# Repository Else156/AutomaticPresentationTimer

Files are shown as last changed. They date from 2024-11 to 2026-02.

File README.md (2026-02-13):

# 物理ベル式 プレゼンテーションタイマー 

Raspberry Pi Pico、SSD1306 OLEDディスプレイ、ソレノイド、およびチンベルを使用したプレゼンテーションタイマーです。
設定した時間（例：予鈴、中間鈴、終了鈴）になると、物理的なベルを「チン！」と鳴らして知らせます。
操作にはRGBロータリーエンコーダを使用し、直感的なメニュー操作と時間設定が可能です。

## ✨ 特徴

* **物理ベル鳴動**: ソレノイドを使用し、設定時間にチンベルを鳴らします。
* **3段階のアラーム設定**: 1回目（1回鳴る）、2回目（2回鳴る）、終了時（3回鳴る）の時間を個別に設定可能。
* **直感的なUI**: ロータリーエンコーダを回して選択・数値変更、押し込んで決定。
* **設定保存機能**: 設定した時間は内蔵フラッシュに保存され、電源を切っても保持されます。
* **加速スクロール**: 時間設定時、エンコーダを速く回すと数値が大きく変化する加速処理を搭載。
* **OLEDディスプレイ**: 現在の残り時間、設定状態、操作ガイドを分かりやすく表示。

## 🛠 ハードウェア構成

### 使用部品

| 部品名 | 型番 | URL | 備考 |
| :--- | :--- | :--- | :--- |
| Raspberry Pi Pico | SC0915 | [購入先URL](https://akizukidenshi.com/catalog/g/g116132/) | |
| 有機ELディスプレイ(OLED) 白色 |  | [購入先URL](https://akizukidenshi.com/catalog/g/g112031/)| |
| イルミネーションロータリーエンコーダ用ピッチ変換基板 | SFE-BOB-11722 | [購入先URL](https://www.switch-science.com/products/1308?srsltid=AfmBOopGGrrqZFvyvS5xYhzGZG8HVmHDNQKUY4yKhhwYDoHrCVhfIAhd) | 廃盤だが千石電商では販売(2026年1月時点） |
| ソレノイド | ZHO-0420S-05A4.5(5V) | [購入先URL](https://akizukidenshi.com/catalog/g/g110761//) | |
| NchパワーMOSFET | 2SK4017(Q) | [購入先URL](https://akizukidenshi.com/catalog/g/g107597/) | |
| カーボン抵抗　10kΩ | RD25S 10K | [購入先URL](https://akizukidenshi.com/catalog/g/g125103/) | |
| 汎用整流用ダイオード 1000V1A | 1N4007-B | [購入先URL](https://akizukidenshi.com/catalog/g/g108327/) | |
| 電解コンデンサー1000μF35V | 35ZLH1000MEFC12.5X20 | [購入先URL](https://akizukidenshi.com/catalog/g/g102722/) | |
| チェック端子(テストポイント) | TEST-22 | [購入先URL](https://akizukidenshi.com/catalog/g/g112216/) | |
| チンベル（卓上ベル） |  |  | |

### 🔌 配線 (Pinout)

`hardware.py` のデフォルト設定に基づく配線図です。

| 部品 | ピン名 | Pico GPIO | 備考 |
| :--- | :--- | :--- | :--- |
| **OLED (I2C)** | SDA | GP0 | |
| | SCL | GP1 | |
| | VCC/GND | - | 3.3V / GND |
| **Encoder** | A相 (CLK) | GP10 | Pull-Up設定 |
| | B相 (DT) | GP11 | Pull-Up設定 |
| | Switch (SW)| GP12 | Pull-Up設定 (Active Low) |
| | GND | - | 共通GND |
| **Solenoid** | Gate/Base | GP15 | **要ドライバ回路** |

> [!WARNING]
> **警告**: ソレノイドをGPIOピン(GP15)に直接接続しないでください。過電流と逆起電力によりPicoが破損します。必ずMOSFET等を使用したドライバ回路と、保護用ダイオードを組み込んでください。

## 📂 ファイル構成

プロジェクトは機能ごとにモジュール化されています。

```text
.
├── circuit/                               # 回路設計関連
│   ├── AutomaticPresentationTimer_v1.0    # Kicadデータが格納
|   └── library/KiCad-RP-Pico-main         # Kicadでの使用ライブラリが格納
├── src/                       # ソースコード
│   ├── main.py                # エントリーポイント。状態遷移と設定の保存/読込を管理
│   ├── hardware.py            # GPIO制御（ソレノイド、エンコーダ、ボタン）
│   ├── display.py             # SSD1306への描画処理
│   ├── presentation_timer_mode.py # タイマー計測・実行モードのロジック
│   ├── setting_mode.py        # メニュー選択モードのロジック
│   ├── edit_mode.py           # 時間設定変更モードのロジック
|   └── settings.json          # 設定保存ファイル (初回実行時に自動生成)
└── README.md
```

> [!WARNING]
> **警告**: プログラムを実行する場合は、ディスプレイ用ドライバライブラリとしてssd1306.pyを得る必要があります。

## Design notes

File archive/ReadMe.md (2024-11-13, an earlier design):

# 自動プレゼンテーションタイマー
## 仕様について
|機器 |型番 |価格 |URL |
|---|---|---|---|
|マイコン |Raspberry Pi Pico |770円 |https://akizukidenshi.com/catalog/g/g116132/ |
|ディスプレイ |SC1602BSLB-XA-GB-K　|980円(購入済み) |https://akizukidenshi.com/catalog/g/g100038/　|
|ソレノイド |ZHO-0420S-05A4.5(5V)　|750円(購入済み) |https://akizukidenshi.com/catalog/g/g110761/|
|MOSFET |IRLU3410PBF　|100円 |https://akizukidenshi.com/catalog/g/g106025/
|整流用ダイオード |1000V1A 1N4007-B　|100円 |https://akizukidenshi.com/catalog/g/g108327/

## 開発環境について
### 仮想環境の導入方法
```
source .venv/bin/activate
```

### ライブラリのインストール
```
pip install -r requirements.txt
```

### VS Code の拡張機能のインストール
1. MicroPico のインストール
VS Code の 拡張機能 をクリックし、 micropico と入力して検索します。<br>
インストール をクリックして、拡張機能をインストールします。


2. MicroPico の初期設定
VS Code の 表示(V) → コマンドパレット をクリックします。<br>

MicroPico: Configure project と入力して Enter キー を押下します。


参考資料は以下に示す<br>
https://qiita.com/IoriGunji/items/ebe6cefd3562639f7ca2

### Raspberry Pi Pico の準備
1. ファームウェアのダウンロード
Raspberry Pi 財団のサイトからファームウェアをダウンロードします。<br>
Raspberry Pi Pico を選んでください。<br>
https://www.raspberrypi.com/documentation/microcontrollers/micropython.html#drag-and-drop-micropython


2. ファームウェアの書き込み
Raspberry Pi Pico の BOOTSET ボタンを押しながら、 USB ケーブルで PC に接続します。

ダウンロードしたファームウェアを RPI-RP2 にドロップします。

ファームウェアの転送が完了すると、 Raspberry Pi Pico が自動的に再起動します。<br>
以上で、ファームウェアの書き込みは完了です。<br>
以降は USB シリアル通信経由で REPL にアクセスできます。<br>

参考資料は以下に示す<br>
https://qiita.com/IoriGunji/items/ebe6cefd3562639f7ca2

## Python コードの実行準備
Raspberry Pi Pico を USB ケーブルで PC に接続します。（※ BOOTSET ボタンは押しません）<br>
VS Code のステータスバーの Toggle board connection ボタンが Pico Connected になっていることを確認します。
Pico Disconnected になっている場合はクリックして Raspberry Pi Pico に接続します。

VS Code のステータスバーの Run current file ボタンをクリックして、実行します。
ボタンの表記が Run から Stop に変わります。

Raspberry Pi Pico 本体の LED が点滅することを確認します。

参考資料は以下に示す<br>
https://qiita.com/IoriGunji/items/ebe6cefd3562639f7ca2

## Pythonコードの書き込み
VS Code の 表示(V) をクリックします。

コマンドパレット をクリックします。

`>MicroPico: Upload current file to Pico` と入力して、 Enter キー を押下します。

参考資料は以下に示す<br>
https://qiita.com/IoriGunji/items/ebe6cefd3562639f7ca2

## Pythonコードの実行（スタンドアローン）
Raspberry Pi Pico の USB ケーブルを PC から外し、 USB 充電器やモバイルバッテリーなどに接続します。<br>
LED が点滅すれば OK です。<br>
参考資料は以下に示す<br>
https://qiita.com/IoriGunji/items/ebe6cefd3562639f7ca2

## 参考文献
### Raspberry Pi Picoについて
https://sozorablog.com/raspberry-pi-pico/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
### ソレノイドの回路など
https://highso.hatenablog.com/entry/2019/02/25/180000
https://ameblo.jp/solcon/entry-12278991497.html

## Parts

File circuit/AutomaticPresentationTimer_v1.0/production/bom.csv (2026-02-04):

Designator | Footprint | Quantity | Value | LCSC Part #
C1 | CP_Radial_D10.0mm_P5.00mm | 1 | 1000µF 16V
D1 | D_DO-41_SOD81_P10.16mm_Horizontal | 1 | D
H1, H2, H3, H4 | MountingHole_3.2mm_M3 | 4 | MountingHole
J1 | PinSocket_1x05_P2.54mm_Vertical | 1 | Conn_01x05
J2 | PinSocket_1x03_P2.54mm_Vertical | 1 | Conn_01x03
J3 | JST_PH_B2B-PH-K_1x02_P2.00mm_Vertical | 1 | ZHO-0420S-05A4.5(5V)
J4 | PinSocket_1x04_P2.54mm_Vertical | 1 | ディスプレイモジュール
Q1 | TO-251-3_Vertical | 1 | 2SK4017
R1 | R_Axial_DIN0207_L6.3mm_D2.5mm_P7.62mm_Horizontal | 1 | 10k
TP1 | TestPoint_THTPad_D2.0mm_Drill1.0mm | 1 | 5V
TP2 | TestPoint_THTPad_D2.0mm_Drill1.0mm | 1 | 3.3V
TP3 | TestPoint_THTPad_D2.0mm_Drill1.0mm | 1 | GND
TP4 | TestPoint_THTPad_D2.0mm_Drill1.0mm | 1 | SDA
TP5 | TestPoint_THTPad_D2.0mm_Drill1.0mm | 1 | SCL
TP6 | TestPoint_THTPad_D2.0mm_Drill1.0mm | 1 | GATE
U1 | RPi_Pico_SMD_TH | 1 | Pico

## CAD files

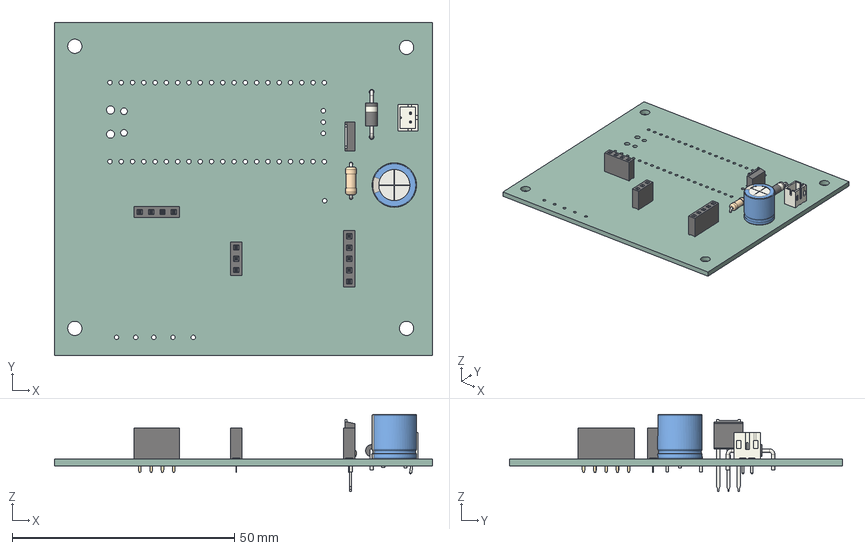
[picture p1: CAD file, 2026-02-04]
circuit/AutomaticPresentationTimer_v1.0/AutomaticPresentationTimer_v1.0.step
85.1 x 74.9 x 17.3 mm
R_Axial_DIN0207_L63mm_D25mm_P762mm_Horizontal
PinSocket_1x03_P254mm_Vertical
TO-251-3_Vertical
PinSocket_1x04_P254mm_Vertical
CP_Radial_D100mm_P500mm
PinSocket_1x05_P254mm_Vertical
D_DO-41_SOD81_P10.16mm_Horizontal
JST_B2B_PH_K
AutomaticPresentationTimer_v1.0_PCB

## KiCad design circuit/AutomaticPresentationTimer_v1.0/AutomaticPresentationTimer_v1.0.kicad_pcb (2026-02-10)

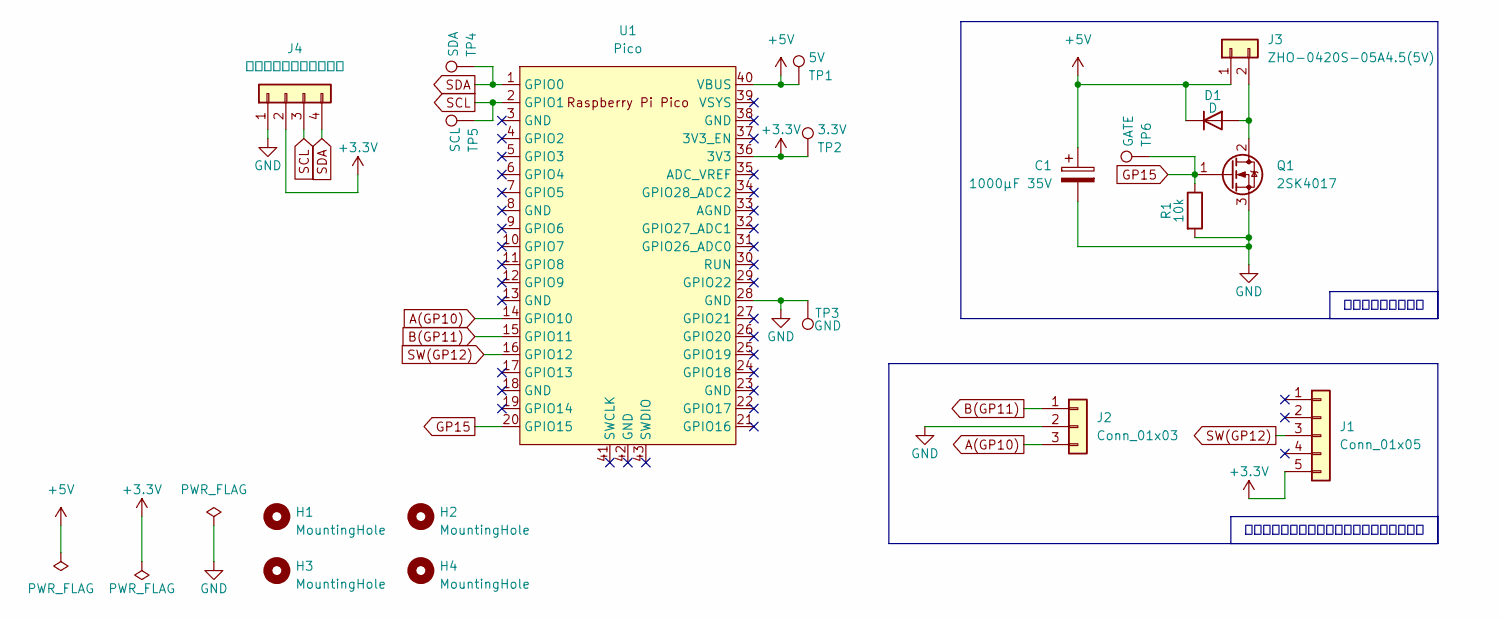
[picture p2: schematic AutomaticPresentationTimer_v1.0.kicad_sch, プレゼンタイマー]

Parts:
C1: 1000µF 35V; CP_Radial_D10.0mm_P5.00mm
D1: D; D_DO-41_SOD81_P10.16mm_Horizontal
H1, H2, H3, H4: MountingHole; MountingHole_3.2mm_M3
J1: Conn_01x05; PinSocket_1x05_P2.54mm_Vertical
J2: Conn_01x03; PinSocket_1x03_P2.54mm_Vertical
J3: ZHO-0420S-05A4.5(5V); JST_PH_B2B-PH-K_1x02_P2.00mm_Vertical
J4: ディスプレイモジュール; PinSocket_1x04_P2.54mm_Vertical
Q1: 2SK4017; TO-251-3_Vertical
R1: 10k; R_Axial_DIN0207_L6.3mm_D2.5mm_P7.62mm_Horizontal
TP1: 5V; TestPoint_THTPad_D2.0mm_Drill1.0mm
TP2: 3.3V; TestPoint_THTPad_D2.0mm_Drill1.0mm
TP3: GND; TestPoint_THTPad_D2.0mm_Drill1.0mm
TP4: SDA; TestPoint_THTPad_D2.0mm_Drill1.0mm
TP5: SCL; TestPoint_THTPad_D2.0mm_Drill1.0mm
TP6: GATE; TestPoint_THTPad_D2.0mm_Drill1.0mm
U1: Pico; RPi_Pico_SMD_TH

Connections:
+3.3V: J1.5, J4.2, TP2.1, U1.36 (3V3)
+5V: C1.1, D1.1 (K), J3.1, TP1.1, U1.40 (VBUS)
A(GP10): J2.3, U1.14 (GPIO10)
B(GP11): J2.1, U1.15 (GPIO11)
GND: C1.2, J2.2, J4.1, Q1.3 (S), R1.2, TP3.1, U1.28 (GND)
GP15: Q1.1 (G), R1.1, TP6.1, U1.20 (GPIO15)
unnamed: D1.2 (A), J3.2, Q1.2 (D)
SCL: J4.3, TP5.1, U1.2 (GPIO1)
SDA: J4.4, TP4.1, U1.1 (GPIO0)
SW(GP12): J1.3, U1.16 (GPIO12)

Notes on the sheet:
プッシュスイッチ付きロータリーエンコーダ
ソレノイド動作回路

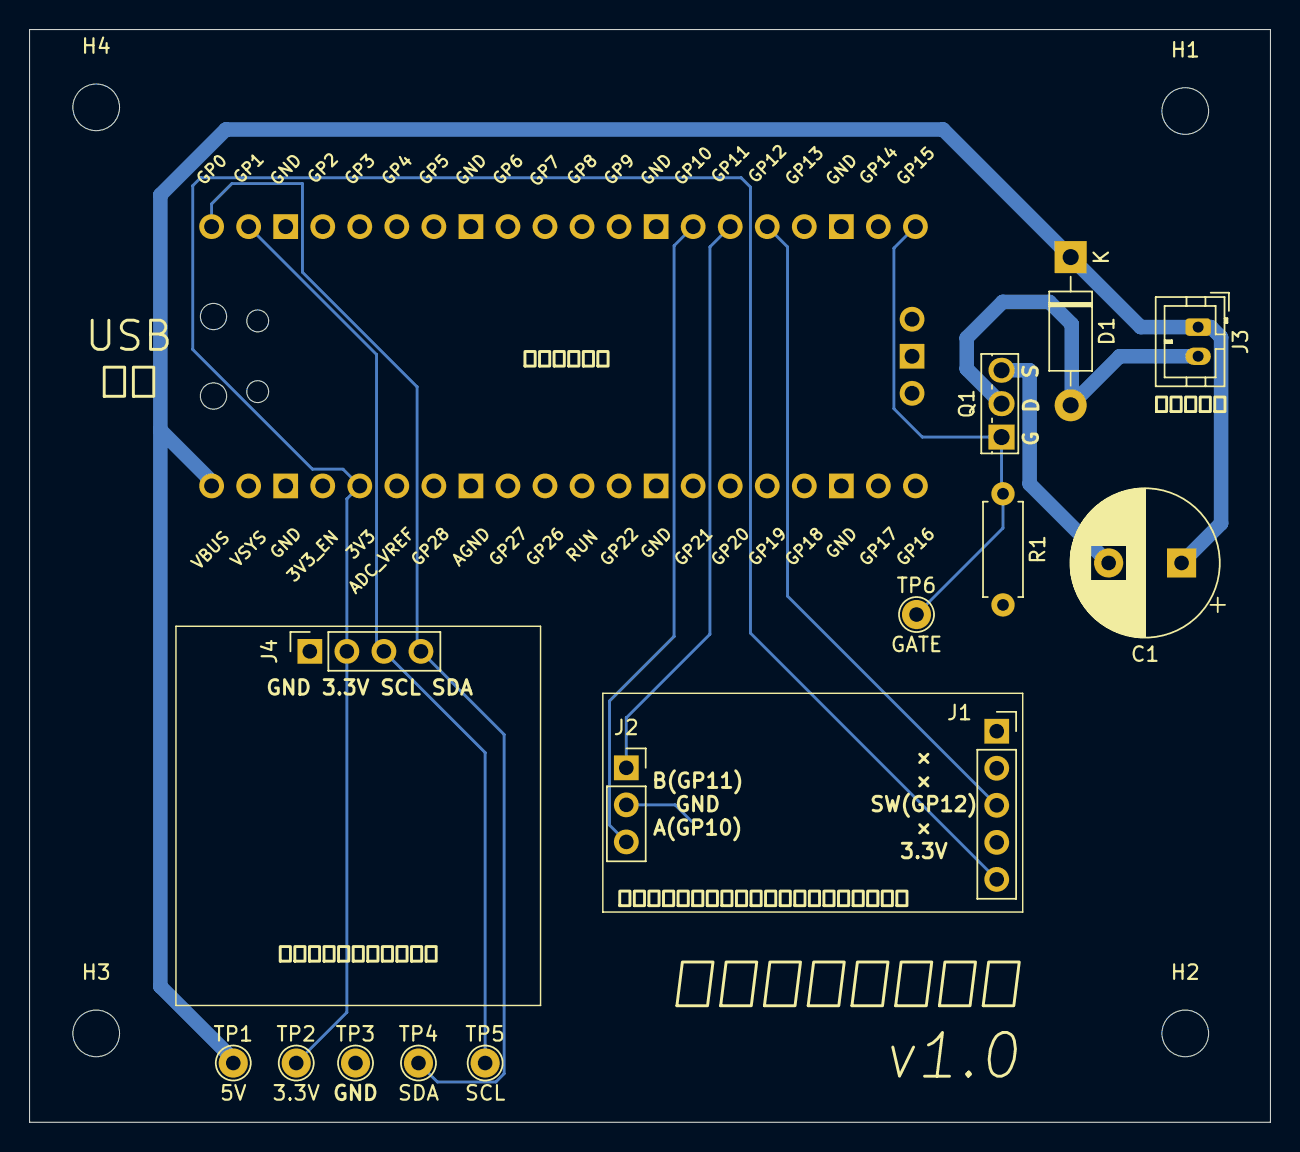
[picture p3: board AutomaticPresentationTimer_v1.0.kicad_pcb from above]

Board: 2 copper layers, 85.1 x 74.9 mm, 19 parts (1 on the bottom side), 10 nets.

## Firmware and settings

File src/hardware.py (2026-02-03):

import machine
import time

class HardwareInterface:
    """
    ハードウェア（GPIO）を管理するクラス
    - ソレノイドの駆動
    - RGBロータリーエンコーダの回転検知
    - エンコーダ内蔵ボタンのイベント検知
    """

    # --- ピン定義 (配線に合わせて変更してください) ---
    SOLENOID_PIN_NUM = 15   # ソレノイド
    
    # ロータリーエンコーダ用ピン
    ENC_A_PIN_NUM = 10      # 回転検知 A相 (CLK)
    ENC_B_PIN_NUM = 11      # 回転検知 B相 (DT)
    BUTTON_PIN_NUM = 12     # スイッチ (SW)

    # --- 設定値 ---
    SOLENOID_ON_MS = 60        # ソレノイド通電時間
    SOLENOID_INTERVAL_MS = 250 # 連打間隔
    
    LONG_PRESS_MS = 800     # 長押し閾値
    DEBOUNCE_MS = 50        # ボタンのチャタリング防止
    
    STEPS_PER_CLICK = 4     # ソレノイドの分解能(1クリックで内部カウンタがいくつ進むか)
    
    def __init__(self):
        # 1. ソレノイド初期化
        self.solenoid = machine.Pin(self.SOLENOID_PIN_NUM, machine.Pin.OUT)
        self.solenoid.value(0) 

        # 2. エンコーダ回転用ピン初期化 (PullUp推奨)
        self.enc_a = machine.Pin(self.ENC_A_PIN_NUM, machine.Pin.IN, machine.Pin.PULL_UP)
        self.enc_b = machine.Pin(self.ENC_B_PIN_NUM, machine.Pin.IN, machine.Pin.PULL_UP)
        
        # 回転量保持用変数（端数もここに溜まり続ける）
        self._rotation_counter = 0
        
        # 割り込み設定 (A相の値が変わった瞬間に _rotary_handler を実行)
        self.enc_a.irq(trigger=machine.Pin.IRQ_RISING | machine.Pin.IRQ_FALLING, handler=self._rotary_handler)
        self.enc_b.irq(trigger=machine.Pin.IRQ_RISING | machine.Pin.IRQ_FALLING, handler=self._rotary_handler)
        self.last_encoded = (self.enc_a.value() << 1) | self.enc_b.value()

        # 3. ボタン初期化 (ロータリーエンコーダはコモンアノードデバイスのためPULL_DOWNに設定)
        self.button = machine.Pin(self.BUTTON_PIN_NUM, machine.Pin.IN, machine.Pin.PULL_DOWN)

        # ボタン状態管理用変数
        self.last_press_start = 0
        self.is_pressing = False
        self.long_press_triggered = False

    def _rotary_handler(self, pin):
        """
        回転検知用の割り込みハンドラ
        (ユーザーが直接呼ぶものではありません)
        """
        # 現在の状態を読み取る
        MSB = self.enc_a.value() # MSB = most significant bit
        LSB = self.enc_b.value() # LSB = least significant bit
        
        encoded = (MSB << 1) | LSB
        sum_val = (self.last_encoded << 2) | encoded
        
        # 状態遷移テーブルのようなロジックで回転方向を判定
        # (一般的なエンコーダの遷移パターン: 0b1101, 0b0100, 0b0010, 0b1011 が1方向)
        if sum_val == 0b1101 or sum_val == 0b0100 or sum_val == 0b0010 or sum_val == 0b1011:
            self._rotation_counter += 1
        elif sum_val == 0b1110 or sum_val == 0b0111 or sum_val == 0b0001 or sum_val == 0b1000:
            self._rotation_counter -= 1
            
        self.last_encoded = encoded

    def get_rotation_delta(self):
        """
        前回のチェック以降の「クリック数」を取得する
        """
        # 必要なステップ数（例:4）に達しているかチェック
        # int()キャストを使うことで、0方向への切り捨てを行う（例: 3/4=0, -3/4=0）
        clicks = int(self._rotation_counter / self.STEPS_PER_CLICK)

        if clicks != 0:
            # 確定したクリック分だけカウンタから減算する
            # 例: counterが5なら、1クリック返して、counterは1残る
            self._rotation_counter -= (clicks * self.STEPS_PER_CLICK)
            return clicks
        
        return 0

    def ring_bell(self, times):
        """指定回数ベルを鳴らす"""
        print(f"[Hardware] ベルを{times}回鳴らします")
        for i in range(times):
            self.solenoid.value(1)
            time.sleep_ms(self.SOLENOID_ON_MS)
            self.solenoid.value(0)
            if i < times - 1:
                time.sleep_ms(self.SOLENOID_INTERVAL_MS)

    def get_button_event(self):
        """
        ボタンイベントの検出 (Active Low対応版)
        Return: "SHORT_PRESS", "LONG_PRESS", None
        """
        current_time = time.ticks_ms()
        
        # ロータリーエンコーダのスイッチは押すとLOW(0)になるため論理を反転
        is_pressed = (self.button.value() == 1)
        
        event = None

        if is_pressed:
            if not self.is_pressing:
                # --- 押し始め ---
                self.is_pressing = True
                self.long_press_triggered = False
                self.last_press_start = current_time
            else:
                # --- 押している最中 ---
                duration = time.ticks_diff(current_time, self.last_press_start)
                if duration > self.LONG_PRESS_MS and not self.long_press_triggered:
                    self.long_press_triggered = True
                    event = "LONG_PRESS"
        
        else: # ボタンが離されている状態
            if self.is_pressing:
                # --- 離した瞬間 ---
                self.is_pressing = False
                duration = time.ticks_diff(current_time, self.last_press_start)
                
                if not self.long_press_triggered and duration > self.DEBOUNCE_MS:
                    event = "SHORT_PRESS"

        return event

# --- 動作確認テスト ---
if __name__ == "__main__":
    hw = HardwareInterface()
    print("ハードウェアテスト開始: エンコーダを回すか押してください...")
    
    try:
        while True:
            # 1. 回転のチェック
            delta = hw.get_rotation_delta()
            if delta != 0:
                # エンコーダの精度によっては 2や4ずつ進むことがあるので適宜割る
                # 例: 実際の1クリックで値が2増えるなら delta // 2 を使う
                direction = "右(CW)" if delta > 0 else "左(CCW)"
                print(f"回転検知: {direction} カウント:{delta}")

            # 2. ボタンのチェック
            evt = hw.get_button_event()
            if evt:
                print(f"ボタン検知: {evt}")
                if evt == "SHORT_PRESS":
                    hw.ring_bell(1)
                elif evt == "LONG_PRESS":
                    hw.ring_bell(2)
            
            time.sleep(0.01) # CPU負荷軽減
            
    except KeyboardInterrupt:
        print("終了")

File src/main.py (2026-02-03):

import time
import json
import machine

# 自作モジュール
import hardware
import display
from presentation_timer_mode import PresentationTimerMode, TimerStatus
from setting_mode import SettingMode
from edit_mode import EditMode

# --- 設定ファイル管理 ---
SETTINGS_FILE = "settings.json"

def load_settings():
    """設定をJSONから読み込む。なければデフォルト値を返す"""
    default_settings = [7, 10, 15] # 単位は「分」
    try:
        with open(SETTINGS_FILE, "r") as f:
            data = json.load(f)
            print("設定をロードしました:", data)
            return data
    except (OSError, ValueError):
        print("設定ファイルが見つかりません。デフォルトを使用します。")
        return default_settings

def save_settings(settings):
    """設定をJSONに保存する"""
    try:
        with open(SETTINGS_FILE, "w") as f:
            json.dump(settings, f)
            print("設定を保存しました:", settings)
    except OSError as e:
        print("保存エラー:", e)

# --- メインループ ---
def main():
    # 1. ハードウェア初期化
    hw = hardware.HardwareInterface()
    
    # 2. モードインスタンス生成
    timer_mode = PresentationTimerMode(hw)
    setting_mode = SettingMode(hw)
    edit_mode = EditMode(hw)
    
    # 3. 設定ロード
    bell_settings = load_settings()
    
    # 状態管理定数
    STATE_MENU = 0
    STATE_EDIT = 1
    STATE_TIMER = 2
    
    current_state = STATE_MENU
    selected_edit_index = 0 # どの時間を編集しているか (0-2)

    print("システム起動")

    while True:
        if current_state == STATE_MENU:
            # --- Setting Mode ---
            action = setting_mode.run()
            
            if action == 3: # "START TIMER" が選ばれた
                current_state = STATE_TIMER
            else:           # 設定項目(0, 1, 2)が選ばれた
                selected_edit_index = action
                current_state = STATE_EDIT

        elif current_state == STATE_EDIT:
            # --- Edit Mode ---
            # 編集する項目のタイトルを決める
            titles = ["1st Bell", "2nd Bell", "3rd Bell"]
            current_title = titles[selected_edit_index]
            current_val = bell_settings[selected_edit_index]
            
            # 編集モード実行 -> 新しい値を受け取る
            new_val = edit_mode.run(current_title, current_val)
            
            # 値を更新して保存
            bell_settings[selected_edit_index] = new_val
            save_settings(bell_settings)
            
            # メニューに戻る
            current_state = STATE_MENU

        elif current_state == STATE_TIMER:
            # --- Presentation Timer Mode ---
            # タイマー実行 (ブロック処理)
            result = timer_mode.run(bell_settings)
            
            # タイマー終了後、または長押し中断後の処理
            if result == TimerStatus.GO_TO_SETTINGS or result == TimerStatus.FINISHED:
                current_state = STATE_MENU
            
            # エラー等の場合もとりあえずメニューへ
            else:
                current_state = STATE_MENU

        # CPU休憩 (モード遷移の間)
        time.sleep(0.1)

if __name__ == "__main__":
    try:
        main()
    except KeyboardInterrupt:
        print("\nプログラムを終了します。")

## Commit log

2024-09-24 イメージ図を作成
2024-09-27 vscodeでArudinoを使えるように変更
2024-10-01 vscodeでarduino環境作り途中
2024-10-01 タイマーとディスプレイの大きさを合わせた
2024-10-08 10月5日作業分
2024-10-08 タイマー部分の作成
2024-10-08 環境作成
2024-10-08 デバック用出力を追加
2024-11-12 プログラム加筆
2024-11-12 イメージ図にHDMIポート追加
2024-11-12 ソレノイド追加
2024-11-12 タイマー機能動作確認済み
2024-11-13 参考文献の追加
2024-11-13 11月13日作業分
2025-04-14 プログラム変更
2025-08-18 ディレクトリ構成変更
2025-08-18 プログラム修正
2025-08-19 TODOリストのURLを追記
2025-11-30 ラズパイピコでソレノイドを動かせるようにした
2025-12-07 待機時間の変更
2026-01-18 不要なファイル削除
2026-01-18 概要更新
2026-01-30 ソースコードの立ち位置を記述
2026-01-30 タイマー機能を実装
2026-01-30 不要なインポート文を削除
2026-01-30 状態名変更
2026-01-30 1月31日作業分
2026-02-03 2月4日作業分
    [AutomaticPresentationTimer_v1.0.kicad_pcb, AutomaticPresentationTimer_v1.0.kicad_sch]
2026-02-10 ディレクトリの名前変更
2026-02-10 不要なデータを削除
2026-02-10 コンデンサの名称を修正
    [AutomaticPresentationTimer_v1.0.kicad_pcb, AutomaticPresentationTimer_v1.0.kicad_sch]
2026-02-13 Update README to include circuit design and source code
2026-02-13 Update README with warning for display driver
    Added warning about required display driver library.
